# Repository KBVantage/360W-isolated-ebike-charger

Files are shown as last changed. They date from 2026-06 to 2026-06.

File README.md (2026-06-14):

# 360W E-Bike Charger

A high-efficiency isolated AC-DC charger designed for a 24V 100Ah LiFePO4 battery pack used in e-bike applications.  
The charger accepts universal single-phase AC input from 110–230 Vrms, performs EMC filtering and rectification, converts the power through an LLC resonant stage, and regulates battery charging using CC/CV control coordinated with the BMS.



The design achieves up to 24V at 15A peak output current with approximately 94% efficiency at the operating point.  
The control and monitoring architecture uses an STM32L0 microcontroller, while Python scripts were used to support test automation and measurement analysis.  
Design capture was done in Altium Designer, circuit verification was supported with LTspice, and firmware development used STM IDE.

---

## Overview

This project documents the complete development flow of a 360W isolated e-bike charger, from initial specification through schematic design, simulation, PCB layout, validation, and thermal testing.  
The architecture was chosen to deliver efficient battery charging for a 24V LiFePO4 pack while maintaining isolation, safety, EMC performance, and reliable current regulation.  
The battery charging profile follows the CCCV method through communication with the BMS, allowing the charger to gradually increase current and then transition into constant-voltage regulation when the battery approaches its target voltage.

---

## Design Flow

This repository is organized to reflect the engineering process used to develop the charger:

1. Define specifications and operating targets.
2. Build the system block diagram.
3. Select and size power-stage components.
4. Simulate critical circuits in LTspice.
5. Capture the schematic and PCB in Altium Designer.
6. Develop embedded control and measurement firmware in STM32 IDE.
7. Assemble the PCB and generate manufacturing files.
8. Validate the prototype with bench testing and thermal measurements.
9. Analyze measured data with Python automation.

This structure is intended to show not only the final design, but also the reasoning behind each stage of the implementation.

---

## Specifications

### Input
- 110–230 Vrms, single-phase AC input.
- EMC filter at the input stage.
- Common-mode filtering for conducted noise reduction.
- 10A fuse protection.
- Bulk capacitance after rectification.
- Bridge diode rectifier.

### Power conversion
- LLC resonant converter for isolated power transfer.
- High-voltage primary MOSFETs rated 650V, TO-247 super-junction devices.
- Transformer optimized for the required power and isolation.
- Synchronous rectification on the secondary side with SR controller.
- 60V LFPAK56 MOSFETs on the secondary rectifier.

### Output and battery interface
- 24V LiFePO4 battery pack, 100Ah.
- BMS communication for CCCV charging control.
- Peak output current: 15A.

### Control and low-voltage power
- STM32L0 microcontroller for system monitoring and charge control.
- 12V, 5V, and 3.3V rails generated from the battery side using buck regulators and LDOs.
- Isolation used where required for safety and signal integrity.

---

## System Architecture

The charger begins with the AC input stage, where EMI and common-mode filtering reduce noise before the line is protected by a fuse and rectified by a bridge diode stage.  
The rectified DC bus is smoothed with bulk capacitance and then processed by the LLC resonant converter, which provides efficient isolated power transfer at 360W.  
The transformer transfers energy across the isolation barrier, and synchronous rectification on the secondary side improves efficiency compared to passive rectification, especially at higher current.

The battery-side control system communicates with the BMS to coordinate CCCV charging.  
Current and voltage are measured at multiple stages of the power path so the charger can regulate the output safely and transition smoothly through the charging phases.  
Low-voltage housekeeping supplies are derived from the battery side using buck converters and LDOs to power the MCU and auxiliary circuitry.

---

## Component Selection

### Input stage
The fuse was selected to protect the charger against abnormal current conditions and fault scenarios.  
The EMC filter and common-mode choke were chosen to reduce conducted emissions and improve input-side noise suppression.  
Bulk capacitance was sized to support the rectified bus ripple and maintain stable energy storage after the bridge rectifier.

### Primary power stage
The primary switches are 650V TO-247 super-junction MOSFETs selected for voltage margin, thermal robustness, and availability during early hardware bring-up.  
This stage is planned for a later GaN update to further reduce switching losses and improve power density.  
The LLC topology was selected because it offers soft-switching behavior and high efficiency at medium power levels.

### Secondary power stage
The synchronous rectifier uses 60V LFPAK56 MOSFETs chosen for low conduction loss and compact package size.  
The SR controller manages timing to reduce diode-like losses on the secondary side and improve thermal performance.  
This is especially useful in a 24V, 15A charger where secondary conduction losses become significant.

### Control and sensing
The STM32L0 was selected for its low-power operation, compact integration, and flexible peripheral set.  
It supports the measurement, sequencing, communication, and supervisory logic needed for a charger platform.  
Its ultra-low-power characteristics also make it suitable for auxiliary management and standby behavior.

---

## Charging Method

The charger supports CCCV charging by communicating with the BMS (19 V to 29.2 V according to the battery charging profile).  
During constant-current operation, the output current is regulated to charge the battery quickly and safely.  
As the battery voltage rises, the charger transitions into constant-voltage mode, gradually reducing current while maintaining the target voltage until the battery is nearly full.

This approach is well-suited to LiFePO4 chemistry because the battery benefits from controlled charging and stable voltage limits.  
Measurement of current and voltage at different stages allows the charger to track charging progress and maintain the desired charge profile.  
The result is a controlled and efficient charging process with reduced stress on the battery pack.

---

## Repository Contents

This repository includes the following design artifacts:

- Block diagram.
- Schematic files.
- PCB layout files.
- 3D STEP files.
- BOM.
- Manufacturing outputs.
- Simulation files.
- Measurement results.
- Thermal images.
- Waveform captures.

These files provide a full record of the design process from concept to validation.

---

## Schematic and Simulation

This section can explain how the simulated waveforms were used to verify resonant tank behavior, switching timing, output ripple, and rectifier performance before hardware fabrication.



Input - CM filter - bridge rectifier - boost PFC Schematic


LLC converter - SR rectifier Schematic


Relay control to connect the battery to the charging schematic.


```md

```

---

## PCB Layout

The PCB layout maintains 3 mm clearance between neutral and live conductors on the primary side, and 6 mm clearance between primary and secondary domains to support the required isolation barrier and reduce risk of electrical breakdown.
The PCB layout was developed with a strong focus on power integrity, EMI control, and safety isolation. High-frequency switching loops were kept as compact as possible, while sensitive measurement, control, and communication traces were routed away from noisy power nodes. The primary and secondary sections were physically separated to support the isolation barrier, with creepage and clearance considered throughout the board layout and transformer interface. Thermal performance was addressed by spreading losses across the board, using copper for heat dissipation, and positioning major power devices to simplify cooling and reduce local hot spots




```md

```

---

## 3D and Mechanical Design



```md

```

---

## Thermal Results
Thermal measurements were taken to identify hotspots across the primary switches, transformer, synchronous rectifier, and auxiliary power components during load testing. The results provide direct feedback on loss distribution and help verify that the layout and cooling strategy are suitable for continuous operation, while also pointing to opportunities for optimization in the next hardware revision.
Vout 24V Iout 5A, 25C ambient



```md

```

---

## Prototype



```md

```

Current and voltage were measured at multiple stages of the converter, including the AC input, rectified DC bus, primary switching stage, secondary output, and battery connection point. This allowed the design to be verified stage by stage, from input power quality and bus stability to transformer transfer behavior, rectifier performance, output regulation, and battery charging response.

During constant-current charging, the charger maintains a near-constant output current while the battery voltage rises gradually. As the battery approaches its target voltage, the system transitions into constant-voltage mode, where the voltage is held steady and the current naturally tapers down until the battery is nearly full.

---

## Test Automation

Python was used to automate test capture, organize measurement data, and assist with result analysis.  
This helped reduce manual effort during iterative validation and made it easier to compare test runs across multiple operating points.  
The combination of Python and bench instrumentation improved repeatability and allowed faster debugging during bring-up.

Example test activities:
- Capture voltage and current waveforms.
- Log thermal data.
- Compare simulated and measured results.
- Generate plots for design review.

---

## Future Improvements

Planned enhancements for the next revision include:

- Replacing primary MOSFETs with GaN devices.
- Further optimizing efficiency at light load.
- Improving thermal spreading and airflow paths.
- Expanding BMS communication features.
- Refining EMI performance and layout optimization.
- Adding more diagnostic and telemetry functions in firmware.

---

## Software Tools

The following tools were used in the design process:

- Altium Designer for schematic and PCB design.
- LTspice for circuit simulation.
- STM IDE for embedded firmware development.
- Python for test automation and data analysis.

---

## Summary

This 360W e-bike charger project demonstrates a full hardware development flow from specification to validated prototype.  
It combines high-efficiency isolated power conversion, battery-aware CCCV control, embedded supervision, and structured validation.  
The repository is organized to show both the final implementation and the engineering reasoning behind each design stage.

---

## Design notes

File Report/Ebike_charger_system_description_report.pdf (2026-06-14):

# Design of a 360W isolated ebike charger (AC to DC charger)

### Kaone Bogopa, Applications Engineer - Vantage Power

### March 12, 2024

### Abstract

This report presents the complete design and validation of a high-efficiency isolated AC–DC battery charger for 24 V, 100 Ah LiFePO4 battery packs in e-bike and electric mobility applications. The charger accepts universal single-phase AC input from 110–230 Vrms, incorporates EMI filtering and full-bridge rectification, and converts power through a half-bridge LLC resonant stage optimized for soft-switching operation and minimal switching losses. The system delivers a regulated 24 V output at 15 A nominal current, achieving 94Charging is controlled via a constant-current/constant-voltage (CC/CV) algorithm coordinated with the battery management system (BMS) to ensure safe, precise, and optimized charging of LiFePO4 cells. Digital control, real-time monitoring, and fault protection are implemented using an STM32L0 microcontroller, enabling flexible control-loop tuning and advanced protection features. Hardware design, including schematic capture and PCB layout, was developed in Altium Designer, with circuit validation supported by LTspice simulations. Python-based automation tools were used for test execution, data acquisition, and measurement analysis, ensuring repeatable validation and production readiness. The report details measurement techniques, implementation scenarios, and system-level integration for a fully functional, production-ready charger.
This design demonstrates a scalable, high-efficiency charging solution for modern electric mobility systems, combining robust power electronics, intelligent digital control, and manufacturable implementation.

## Contents

### 1 Introduction

This report documents the complete development methodology of a 360 W isolated AC–DC battery charger for 24 V LiFePO4 battery packs in e-bike and light electric mobility applications. The design process encompasses initial specification, system architecture selection, schematic capture, circuit simulation, PCB layout, experimental validation, and thermal performance characterization.

The power conversion architecture employs a half-bridge LLC resonant topology with galvanic isolation, selected for its high efficiency, soft-switching operation (zero-voltage switching for primary MOSFETs and zero-current switching for secondary rectifiers), and excellent electromagnetic compatibility (EMC) performance. The converter accepts universal single-phase input from 110–230 Vrms, input EMI filtering and rectification, and delivers a regulated 20 - 29 V output at 15 A nominal load current with 94% efficiency at the nominal operating voltage.

Battery charging follows a constant-current/constant-voltage (CC/CV) profile, coordinated with the battery management system (BMS) via communication interface. The charger operates in constant-current mode during the bulk charging phase, gradually increasing cell voltage, then transitions to constant-voltage regulation as the battery approaches its target voltage (typically 28.8 V for a 24 V LiFePO4 pack). This charging strategy ensures optimal charging, and prevents overcharging or thermal runaway conditions.

Digital control, real-time monitoring, and fault protection are implemented using an STM32L0 microcontroller, enabling adaptive control-loop tuning, comprehensive protection features (over-voltage, over-current, over-temperature, short-circuit), and flexible system integration. The hardware design was developed in Altium Designer, with circuit-level validation performed using LTspice simulations, and test automation supported by Python-based data acquisition and analysis tools.

This work presents a scalable charging solution that combines high-efficiency power electronics, intelligent digital control, and robust system-level integration.

### 2 Design Flow

This report presented the complete engineering development methodology for the 360 W isolated AC–DC e-bike charger, structured to reflect industry-standard power electronics design practices. The workflow demonstrated a systematic approach from initial specification through final validation, showcasing both technical rigor and production readiness.

- Specification Definition: Defined electrical specifications, operating conditions, and performance targets including input voltage range (110–230 Vrms), output power (360 W), efficiency target (≥ 94%), and safety/regulatory requirements.
- System Architecture: Developed the system block diagram selecting LLC resonant topology with galvanic isolation, CC/CV control strategy, and BMS communication interface.
- Power-Stage Component Selection: Calculated and selected critical power components including MOS-FETs, resonant inductor (Lr), resonant capacitor (Cr), transformer (turns ratio, core selection), output rectifiers, and passive filtering components based on datasheet specifications and application notes.
- Circuit Simulation: Performed circuit-level validation using LTspice for transient analysis, soft-switching verification (ZVS/ZCS), efficiency estimation, and stability assessment of the control loop.
- Schematic and PCB Design: Captured the schematic and executed PCB layout in Altium Designer, incorporating proper impedance control, thermal management, EMC considerations, and high-voltage isolation creepage/clearance requirements.
- Embedded Firmware Development: Implemented digital control loops, BMS communication protocol, real-time monitoring, and fault protection algorithms using STM32L0 microcontroller in STM32 IDE (C/C++).
- PCB Assembly and Manufacturing: Generated manufacturing files (Gerber, BOM, pick-and-place), assembled the PCB, and prepared for prototype validation.
- Prototype Validation: Conducted comprehensive bench testing including input/output characteriza-

360 W isolated e-bike charger
This document belongs to Vantage Power

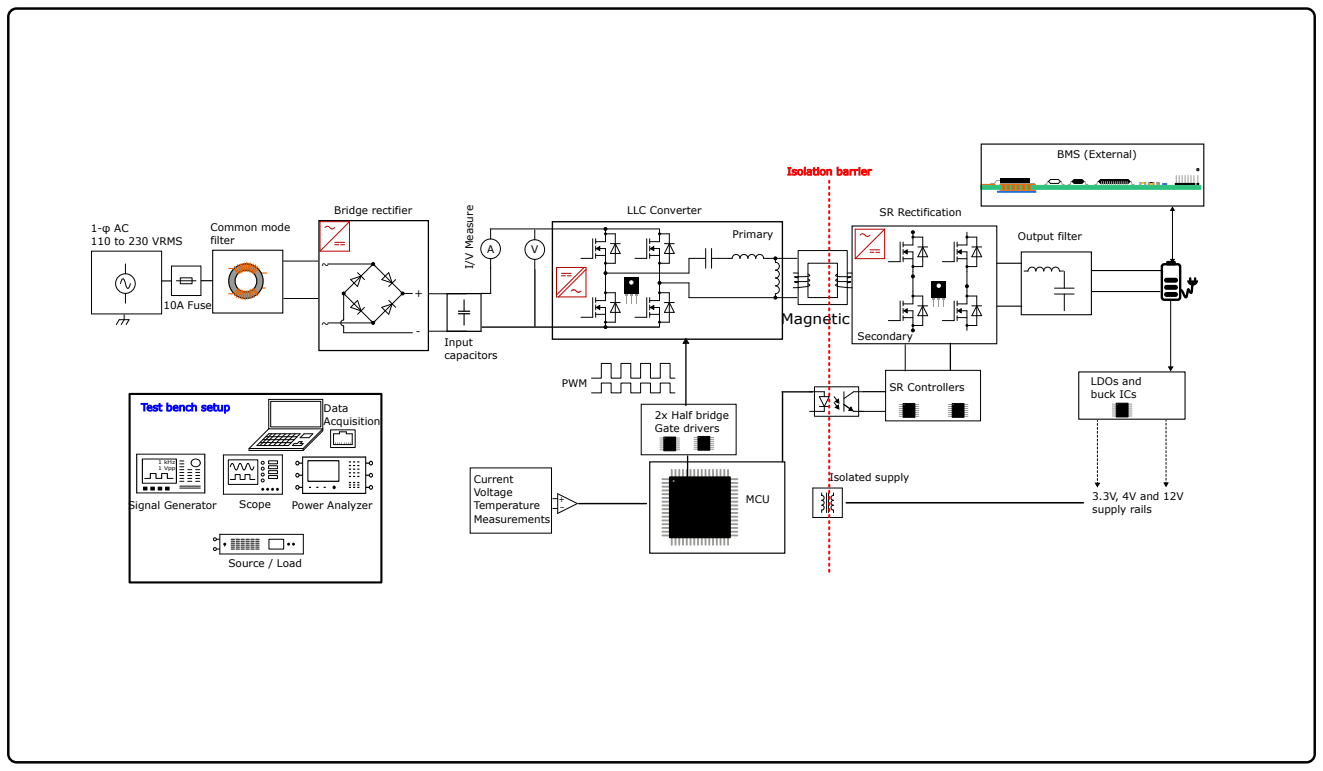
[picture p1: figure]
LLC Converter; Primary; Bridge rectifier; Input capacitors; PWM; Current Voltage Temperature Measurements; Common mode filter; 1-φ AC 110 to 230 VRMS; 10A Fuse; 1 kHz 1 Vpp; Signal Generator; Scope; Source / Load; Power Analyzer; Magnetic; I/V Measure; SR Rectification; SR Controllers; Isolated supply; Secondary; LDOs and buck ICs; Output filter; 2x Half bridge Gate drivers; BMS (External); 3.3V, 4V and 12V supply rails; MCU; Test bench setup; Data; Acquisition; Isolation barrier

Figure 1: E-bike charger block diagram that was adopted

tion, efficiency measurement, load/transient response, EMC pre-compliance, and thermal performance characterization using calibrated instrumentation.

This structured approach demonstrated not only the final design outcome but also the engineering rationale, design trade-offs, and validation methodology behind each implementation stage—reflecting professional engineering practice suitable for production deployment.

### 3 Specifications

The following specifications were provided by the client for the 360 W isolated AC–DC e-bike charger. These define the electrical, safety, and performance requirements for the system.

### 3.0.1 Input Requirements

- Input voltage: 110–230 Vrms single-phase AC, universal input range.
- EMI/EMC filtering: Input-stage EMC filter compliant with IEC 61000-4-6 for conducted emissions reduction.
- Common-mode filtering: Common-mode choke for noise attenuation and conducted interference suppression.
- Protection: Input fuse protection for over-current and short-circuit safeguarding.
- Rectification: Full-bridge diode rectifier for AC-to-DC conversion.
- Bulk capacitance: High-voltage bulk capacitor following rectification for DC bus stabilization.
- Power Factor Correction: Boost-type PFC stage to achieve power factor ≥ 0.9 and reduce input current harmonics.

### 3.0.2 Power Conversion Architecture

- Topology: Half-bridge LLC resonant converter for isolated power transfer with soft-switching operation (ZVS/ZCS).
- Primary MOSFETs: 650 V super-junction MOSFETs in TO-247 package for high-voltage primary switching, optimized for low RDS(on) and fast switching characteristics.
- Transformer: High-frequency isolated transformer optimized for 360 W power transfer, galvanic isolation ≥ 4 kV, and minimal leakage inductance.
- Secondary rectification: Synchronous rectification (SR) using SR controller for improved efficiency and reduced conduction losses.
- Secondary MOSFETs: 60 V LFPAK56 MOSFETs on the secondary rectifier stage, selected for low RDS(on) and compact footprint.

### 3.0.3 Output and Battery Interface

- Battery type: 24 V LiFePO4 battery pack, 100 Ah capacity.
- BMS communication: Digital communication interface with battery management system for CCCV (constant-current/constant-voltage) charging control and safety monitoring.
- Output voltage: Regulated 24 V nominal (charging target: 28.8 V for LiFePO4 pack).
- Peak output current: 15 A maximum continuous charging current (360 W nominal power).

### 3.0.4 Control and Low-Voltage Power Supply

- Microcontroller: STM32L0 ARM Cortex-M0+ microcontroller for digital control loop implementation, system monitoring, BMS communication, and fault protection.
- Voltage rails: 12 V, 5 V, and 3.3 V supply rails generated from the battery-side DC bus using buck regulators and LDOs for gate drive, analog sensing, and digital logic.
- Isolation: Galvanic isolation implemented for high-voltage safety, signal integrity, and compliance with IEC 60950-1/IEC 62368-1 safety standards.

### 4 Block Diagram

Figure 1 presents the complete system block diagram of the 360 W isolated AC–DC e-bike charger, illustrating the power flow architecture, control subsystems, and interface connections. The design follows a two-stage power conversion approach: (1) an input stage with EMC filtering, rectification, and active boost PFC, and (2) an isolated LLC resonant converter with synchronous rectification.

This architecture was selected to achieve high efficiency, galvanic isolation, and excellent EMC performance while meeting IEC 61000-3-2 harmonic current limits.

### 4.0.1 Input Stage: EMC Filtering and Rectification

The input stage begins with an EMI/EMC filter incorporating a common-mode choke to attenuate conducted noise and reduce radiated emissions. This filter serves three critical functions: (1) minimizing radiated and conducted noise on the AC input, (2) reducing the effects of voltage transients from the input source, and (3) protecting the input conductors if a supply failure occurs. The common-mode filter specifically targets conducted noise by presenting high impedance to common-mode currents while allowing differential-mode AC power to pass with minimal attenuation.

Following the EMC filter, a full-bridge diode rectifier converts the AC input to pulsating DC. The bridge rectifier is required for AC–DC power supplies and enables universal input operation (110–230 Vrms). A bulk capacitance following rectification stabilizes the DC bus and filters high-frequency ripple. An inrush current limiter is placed in series with the input to limit the surge current during initial capacitor charging, which can otherwise be 100×greaterthanthenormaloperatingcurrent.

### 4.0.2 Active Power Factor Correction (Boost PFC)

Figure 2: Boost converter topology for the PFC
The boost-type PFC stage is implemented as an active power factor correction circuit to achieve power factor greater than 0.9 and reduce input current harmonics per IEC 61000-3-2. Active PFC brings the power supply’s power factor close to 1.0 by shaping the input current waveform to follow the input voltage waveform, thereby minimizing reactive power and harmonic distortion. This stage is critical for meeting regulatory requirements and reducing stress on the AC mains infrastructure.

Why boost PFC over passive PFC?

Passive PFC using inductors can achieve power factor approximately 0.7–0.8 but requires large, heavy magnetic components and provides limited harmonic attenuation. Active boost PFC achieves power factor greater than 0.95 at compact size and provides a regulated high-voltage DC bus (typically 380–400 V) for the subsequent LLC stage. The regulated DC bus also enables the LLC converter to operate with consistent gain characteristics across the universal input range, which is essential for maintaining ZVS conditions. For e-bike chargers requiring compact size and regulatory compliance, active PFC is the industry-standard choice.

### 4.0.3 Isolated Power Conversion: LLC Resonant

Converter

Figure 3: LLC converter topology The half-bridge LLC resonant converter forms the core power conversion stage, providing isolated power transfer with soft-switching characteristics. The LLC topology was selected over alternative isolated topologies for specific technical reasons.

LLC vs. Hard-Switched Flyback: Flyback converters

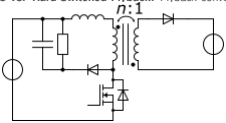
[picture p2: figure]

Figure 4: flyback topology

are simple and cost-effective for low-power applications (less than 100 W) but suffer from high switching losses, poor efficiency.

LLC vs. Phase-Shifted Full-Bridge:

Phase-shifted full-bridge converters offer high efficiency

Figure 5: PFSB topology
and power handling but require complex control (four MOSFETs with precise phase timing) and have higher component count. LLC uses only two primary MOSFETs with simpler frequency-control implementation while achieving comparable efficiency (≥ 94%). For 360 W e-bike charger applications, LLC provides the optimal balance of efficiency, complexity, and cost.

The primary MOSFETs (650 V super-junction devices in TO-247 package) are optimized for low RDS(on) and fast switching characteristics, enabling efficient high-frequency operation (50–200 kHz). Super-junction MOSFETs provide lower RDS(on)

. A product compared to conventional MOSFETs, reducing conduction losses.

The high-frequency isolated transformer is optimized for 360 W power transfer with galvanic isolation ≥ 4 kV and minimal leakage inductance. The transformer serves as the isolation barrier and provides voltage transformation from the high-voltage DC bus to the 24 V output. Parasitic capacitance between primary and secondary windings is a potential EMI source that must be addressed through proper winding layout and shielding.

### 4.0.4 Secondary Rectification: Synchronous Rectifi-

cation (SR)

The synchronous rectification (SR) stage uses actively controlled MOSFETs instead of diodes for output rectification, providing:

- Reduced conduction losses: MOSFET RDS(on) is
significantly lower than diode forward voltage drop Vf
- Higher efficiency: SR can achieve 1–2% efficiency improvement over diode rectification at 15 A output
- Lower thermal stress: Reduced power dissipation decreases heat generation on the secondary side

Why SR over diode rectification? At 15 A output current, a typical Schottky diode with Vf ≈ 0.5 V dissipates

P = Vf × I = 0.5 × 15 = 7.5 W.

Using two diodes in full-wave configuration doubles this to 15 W. In contrast, a 60 V LFPAK56 MOSFET with RDS(on) = 10 mΩ dissipates

P = I

2 × RDS(on) = 15² × 0.01 = 2.25 W.

This represents an 85% reduction in rectification losses, directly contributing to the 94% system efficiency target. SR is essential for high-current, high-efficiency applications.
The 60 V LFPAK56 MOSFETs on the secondary rectifier are selected for low RDS(on) and compact footprint. The LFPAK56 package provides excellent thermal performance with low junction-to-case resistance, enabling efficient heat dissipation.
The SR controller monitors the transformer secondary voltage and drives the MOSFETs with precise timing to achieve ZCS, minimizing reverse-recovery losses.

### 4.0.5 Output Filter and Battery Interface

The output filter consists of capacitors (and optionally a series inductor for L-filter or Pi-filter configuration) to suppress AC ripple superimposed on the DC output. Without output filtering, the peak-to-peak ripple magnitude would equal the DC voltage, which is unacceptable for battery charging. The filter components are placed close to the battery connection to minimize voltage drop caused by load current variations.

The battery interface includes relays for safe connection/disconnection of the battery pack. The relays enable fault isolation (over-current, over-voltage, short-circuit) and support the CCCV charging algorithm by controlling current flow during the charging phases. Connection to the

### 24 V LiFePO4 battery pack (100 Ah) is managed through

the BMS communication interface.

### 4.0.6 Control Subsystem: MCU, Gate Driver, and Sen-

sors

The STM32L0 microcontroller (ARM Cortex-M0+) implements the digital control loop, system monitoring, BMS communication, and fault protection algorithms. The STM32L0 was selected for its:

- Low power consumption (suitable for battery-side control power)
- Adequate PWM resolution and frequency for LLC control (up to 32 MHz clock, 16-bit PWM)
- Built-in ADC channels for current/voltage sensing (12-bit, 2.5 MS/s)
- Communication interfaces (UART/I2C) for BMS interface

Why digital control over analog?
Analog control using PWM controllers (e.g., UC384x family) is simpler but lacks flexibility for adaptive control, complex protection algorithms, and BMS communication. Digital control enables:
(1) adaptive gain tuning for LLC operating across resonant frequency,
(2) comprehensive fault detection with programmable thresholds,
(3) firmware updates for field bug fixes, and
(4) direct BMS communication protocol implementation (e.g., CAN, UART).

For modern e-bike chargers requiring smart features and regulatory compliance, digital control is the preferred approach.
The gate driver circuit provides isolated drive signals to the primary MOSFETs, ensuring proper switching timing and protecting the MCU from high-voltage transients. Gate driver isolation is critical for safety and signal integrity in isolated power converters.

Current and voltage sensors (typically Hall-effect sensors or resistive dividers with isolation) provide feedback for the control loop. The current sensor monitors output charging current for CC mode regulation, while the voltage sensor monitors output voltage for CV mode regulation and BMS communication validation.

### 4.0.7 Low-Voltage Power Supply: Buck Regulators

and LDOs

The low-voltage rails (12 V, 5 V, and 3.3 V) are generated from the battery-side DC bus using buck regulators and

LDOs:

- 12 V rail: Powers gate drivers, SR controllers, and relay coils
- 5 V rail: Supplies analog sensing circuits and peripheral interfaces
- 3.3 V rail: Provides logic power for the STM32L0 MCU

Why buck regulators over linear regulators?
Linear regulators (e.g., 78xx series) dissipate power as heat:

Ploss = (Vin − Vout) × Iout.

For 24 V to 3.3 V conversion at 100 mA, a linear regulator dissipates

P = (24 − 3.3) × 0.1 = 2.07 W,

requiring significant heatsinking. Buck regulators achieve 85–95% efficiency, dissipating only 0.1–0.15 W for the same conversion. For battery-side control power where efficiency and thermal management are critical, buck regulators are essential.
Buck regulators provide efficient DC–DC conversion from the higher battery voltage to required logic levels, while LDOs provide clean, low-noise power for sensitive analog and digital circuits.

### 4.0.8 Thermal and Performance Considerations

The block diagram architecture directly impacts thermal performance and system efficiency:

- Primary side thermal load: LLC resonant operation with ZVS minimizes MOSFET switching losses, reducing primary-side heat generation. The TO-247 package provides adequate thermal dissipation for 650 V, 2–3 A primary current.
- Secondary side thermal load: SR with ZCS minimizes rectifier losses. The LFPAK56 package’s low junction-to-case resistance enables efficient heat transfer to the PCB thermal copper.
- Transformer thermal design: High-frequency operation reduces transformer size but increases core loss. The transformer is optimized for minimal leakage inductance and appropriate core material (ferrite) to balance efficiency and size.
- PFC stage thermal load: The boost PFC dissipates ≈ 2–3 W at 360 W output (assuming 97–98% PFC efficiency), requiring adequate copper area and possibly a small heatsink.

Overall system efficiency of 94% at 15 A output corresponds to ≈ 22 W total power dissipation, which must be managed through PCB thermal copper, component placement, and potentially ventilation or forced air if enclosure thermal resistance is high.

### 4.0.9 Test Instrumentation and Validation Points

The block diagram indicates test instrumentation connection points for prototype validation:

- Input AC voltage and current (for power factor and efficiency measurement)
- DC bus voltage (after PFC)
- LLC switching nodes (for ZVS/ZCS verification)
- Output voltage and current (for CC/CV regulation validation)
- Temperature sensors (MOSFETs, transformer, PFC components)

These instrumentation points support the Python-based test automation described in the Design Flow section, enabling automated data acquisition and post-processing for performance validation.

### 5 Component Selection

This section details the component selection process for the 360 W isolated AC–DC e-bike charger, including mathematical sizing calculations, part requirements, and recommended packages. Components were selected based on datasheet specifications, application notes, and worstcase operating conditions to ensure reliability, efficiency, and regulatory compliance.

### 5.1 Input Stage

The input stage comprises fuse protection, TVS (transient voltage suppression) diode, common-mode (CM) filter, bridge rectifier, boost PFC stage, bulk capacitors, and current/voltage measurement circuits. Each component is sized and selected as follows.

1. Fuse Protection
Function: Over-current and short-circuit protection for the AC input stage.

Selection Criteria:

- Rated current: Ifuse ≥ 1.5 × Iin,max (for inrush current tolerance)
- Voltage rating: Vfuse ≥ 250 Vrms (universal input)
- Time-current characteristic: Fast-blow for rapid fault response

Calculation:
Maximum input current at lowest input voltage (110 Vrms):

Iin,max =

Pout

Vin,min × ηtotal × PF

=

360
110 × 0.94 × 0.95
= 3.68 A

where ηtotal = 94% is total efficiency and PF = 0.95 is power factor.
Fuse rating:

Ifuse = 1.5 × 3.68 = 5.52 A → Select 6 A fuse

Recommended Part: 6 A, 250 Vrms, fast-blow fuse (e.g., Littelfuse 0215006.MXL)
Package: Axial leaded or PCB-mount radial fuse (e.g., 5 × 20 mm)
2. TVS (Transient Voltage Suppression) Diode Function: Protect input stage from voltage transients and surges (e.g., lightning, switching transients).

Selection Criteria:

- Clamping voltage: Vclamp ≥ 1.2 × Vin,max ×

√
2
- Peak pulse power: Ppp ≥ 1000 W (for IEC 61000-4-5 compliance)
- Breakdown voltage: VBR ≈ Vin,max ×

√
2

Calculation: Maximum AC input voltage: Vin,max = 230 Vrms
Vpeak,max = 230√
2 ≈ 325 V

Clamping voltage:

Vclamp = 1.2 × 325 ≈ 390 V

Recommended Part: 390 V clamping TVS diode (e.g., Littelfuse SA390CA, Bourns CDSF390CA)
Package: SMA (DO-214AC) or SMC (DO-214AA) for high power dissipation.
3. Common-Mode (CM) Filter

Function: Attenuate conducted EMI noise and reduce common-mode currents per IEC 61000-4-6.
Selection Criteria:
- Inductance: LCM ≥ 10 mH (for 10–30 MHz attenuation)
- Rated current: ICM ≥ Iin,max = 3.68 A
- Differential-mode capacitance: CDM ≤ 4.7 (to limit leakage current)

Calculation:
For 50 dB attenuation at 150 kHz (EMI start frequency):

LCM =

Zsource
2πf × 10

attenuation
20

=

50
2π × 150 × 10³

× 10².5

≈ 10 mH

where Zsource = 50 Ω is the standard EMI test impedance.

Recommended Part: 10 mH, 5 A common-mode choke (e.g., TDK DSZV2521A-100M, Wurth Electronics 74437346010)
Package: PCB-mount axial or radial choke (e.g., 25 × 21 mm).
4. Bridge Rectifier

Function: Convert AC input to pulsating DC for PFC stage.
Selection Criteria:
- Repetitive peak reverse voltage: VRRM ≥ 1.2×Vin,max×
√
2
- Average forward current: IF(ave) ≥ 1.5 × Iin,max
- Forward voltage drop: VF ≤ 1.0 V (for efficiency)
- Reverse recovery time: trr ≤ 300 ns (slow-recovery acceptable for 50/60 Hz)

Calculation:

VRRM = 1.2 × 230 ×

√
| 2 = 390 V → Select 600 V

IF(ave) = 1.5 × 3.68 = 5.52 A → Select 8 A

Power dissipation at 3.68 A:

Pbridge = VF×Iin = 0.9×3.68 = 3.31 W (two diodes in series)

Recommended Part: 600 V, 8 A bridge rectifier (e.g., STMicroelectronics STPSC8H065, Vishay VS-80MW60) Package: TO-247 or KBU (for 8 A, requires heatsink with Rth ≤ 5 K/W).

5. Boost PFC Stage

Function: Active power factor correction to achieve PF ≥ 0.95 and regulated 390 V DC bus.

5.1 PFC MOSFET
Selection Criteria:
- Drain-source voltage: VDS ≥ 1.2 × Vbus = 1.2 × 390 = 468 V → Select 600 V
- Continuous drain current: ID ≥ 1.5 × Iin,max
- On-resistance: | RDS(on) | ≤ | 0.5
Ω(forlowconductionloss)
- Switching frequency: fsw ≥ 50 kHz (CCM operation)

Calculation:
PFC MOSFET RMS current (CCM boost):

ID,RMS ≈ Iin,max ×

s
Vbus − Vin,peak

Vbus

= 3.68 ×

r
390 − 325
390
= 1.52 A

With 1.5×margin : ID = 1.5 × 1.52 = 2.28 A → Select 4 A
Conduction loss:

Pcond = I

2
D,RMS × RDS(on)

= 1.52² × 0.2

= 0.46 W

for RDS(on) = 0.2 Ω

Recommended Part: 600 V, 4 A super-junction MOSFET (e.g., Infineon IPW60R045, Onsemi NTH6L020N65SF) Package: TO-247 or TO-220 (requires heatsink for 0.46 W

+ switching loss).

5.2 Boost Diode
Selection Criteria:
- Reverse voltage: VRRM ≥ Vbus = 390 V → Select 600 V
- Average forward current: IF(ave) ≥ Iout =

Pout
Vbus

=

360
390 =
0.92 A
- Reverse recovery time: trr ≤ 50 ns (ultrafast/SiC for CCM)
- Forward voltage: VF ≤ 1.2 V

Calculation: With 2 × margin: IF(ave) = 2× 0.92 = 1.84A→ Select 3 A Diode power loss:

Pdiode = VF × Iout = 1.0 × 0.92 = 0.92 W (SiC diode)

Recommended Part: 600 V, 3 A SiC Schottky diode (e.g., Onsemi CS3D06060L, Wolfspeed C3D06060K). Package: TO-247 or TO-220 (SiC diodes have low loss, small heatsink sufficient).

5.3 Boost Inductor

Selection Criteria:

- Inductance: Lboost for CCM operation at minimum input voltage
- Current rating: IL,max ≥ Iin,max +

∆IL
2
- Core material: Ferrite (for 50–100 kHz)
- Saturation current: Isat ≥ 1.2× IL,max

Calculation:
For CCM at Vin,min = 110 Vrms, fsw = 65 kHz:

Lboost =

Vin,peak × (Vbus − Vin,peak)

fsw × Pout × ∆IL

=

155 × (390 − 155)
65 × 10³ × 360 × 0.2 × 3.68 = 280 µH

where ∆IL = 0.2× Iin,max is 20% ripple current. Peak inductor current:

IL,max = Iin,max +

∆IL
2

= 3.68 +

0.2 × 3.68
2
= 4.05 A

With 1.2 × saturation margin:

Isat = 1.2 × 4.05 = 4.86 A → Select 5 A

Recommended Part: 280 , 5 A ferrite inductor (e.g., PULSE Electronics PLT2815-280K, TDK DSL2520-281K) Package: Axial or radial shielded inductor (e.g., 28 × 15 mm).

5.4 PFC Output Capacitor

Selection Criteria:

- Voltage rating: VC ≥ 1.2× Vbus = 468 V → Select 500 V
- Capacitance: Cbus for hold-up time and ripple voltage
- RMS current rating: IC,RMS ≥ Iout
- Low ESR: ESR ≤ 0.5 Ω(forlowrippleloss) Calculation:
For 10 ms hold-up time at full load:

Cbus =

2 × Pout × thold
V

2
bus − V

2
min
=

2 × 360 × 0.01
390² − 300²
= 3.3 µF

where Vmin = 300 V is the minimum PFC output for LLC operation.
Ripple voltage (with ESR = 0.3 Ω) :
∆Vripple = Iout × ESR = 0.92 × 0.3 = 0.28 V (negligible)

Recommended Part: 500 V, 3.3 µ F film capacitor (e.g., Vishay 238D335X5500, WIMA WQP335K500) Package: Radial film capacitor (e.g., 20 × 35 mm).

6. Bulk Capacitors (After Bridge Rectifier)

Function: Stabilize DC bus before PFC stage and filter high-frequency ripple.
Selection Criteria:
- Voltage rating: Vrated ≥ 1.2× Vin,max×

√
2 = 390 V →
Select450V.
- Capacitance: Cbulk ≥ 1 µF/Wforripplef iltering.
- RMS current: IC,RMS ≥ Iin,max.

Calculation:

Cbulk = 1 µF/W × 360 W = 360 µF

Select 2 × 220 µF

Recommended Part: 450 V, 220 µ F electrolytic capacitor (e.g., Nichicon UXW450221, Panasonic EEU-FC450221).
Package: Radial electrolytic (e.g., 25 × 40 mm), use 2 in parallel for current sharing.
7. Current and Voltage Measurement Circuits

7.1 Input Voltage Sensing
Function: Provide scaled AC input voltage feedback to the MCU for PFC control and RMS calculation.

Selection Criteria:

- Voltage divider ratio: VADC =

Vin,peak
N

≤ 3.3 V (MCU
ADC range).
- Impedance: Rtotal ≥ 100 kΩ (for low power loss).
- Precision: ≤ 1% tolerance resistors.

Calculation:

N =

Vin,peak,max

VADC,max

=

325
3.3

= 98.5 → Select N = 100

R1 = 99 kΩ, R2 = 1 kΩ (voltage divider)

Power loss:

Pdivider =

V

2
in,rms
R1 + R2

=

230²
100 × 10³

= 0.53 W

This is acceptable for a 0.5 W to 0.6 W high-voltage resistor string with adequate spacing and thermal margin.

Recommended Part: 99 kΩ, 1 kΩ, 1% tolerance resistors (e.g., Vishay MRS25000, Yageo MFR-25). Package: SMD 2512 for 0.5 W power rating or axial leaded 0.6 W.

7.2 Input Current Sensing

Function: Measure AC input current for PFC control loop and power calculation.

Selection Criteria:

- Sensing method: Hall-effect sensor for AC, noninvasive, or precision shunt resistor.
- Range: Isense ≥ Iin,max = 3.68 A.
- Output: Scaled to 0–3.3 V for MCU ADC.

Calculation:
Using a Hall-effect sensor, for example a 5 A range with 250 mV/A output:

VADC = 3.68 A × 250 mV/A = 0.92 V

This is within the ADC input range.

Recommended Part: 5 A Hall-effect current sensor (e.g., Littelfuse LA55-P, Honeywell CSLA2CD).
Package: PCB-mount through-hole sensor, approximately 20 × 15 × 10 mm.

7.3 PFC Output Voltage Sensing

Function: Monitor the 390 V DC bus for PFC regulation and LLC input validation.

Selection Criteria:

- Voltage divider: N =

390
3.3

= 118 → Select N = 120.
- High-voltage resistors: VR ≥ 200 V per resistor, using series resistors.

Calculation:

R1 = 119 kΩ (use 3 × 40 kΩ in series), R2 = 1 kΩ

Recommended Part: 40 kΩ, 200 V, 1% resistors (e.g., Vishay VSR series) + 1 kΩ, 0.25 W.
Package: SMD 2512 or axial leaded 0.6 W.

7.4 Output Current Sensing

Function: Measure 15 A battery charging current for CC mode regulation.

Selection Criteria:

- Sensing method: Low-RDS(on) MOSFET with current-sense pin or precision resistor.
- Range: Isense ≥ 15 A.
- Power loss: Psense ≤ 0.5 W for efficiency.

Calculation:
Using a precision resistor with Rsense = 5 mΩ:

Psense = I

2

out × Rsense = 15² × 0.005 = 1.125 W

This is too high.
Using Rsense = 2 mΩ:

Psense = 15² × 0.002 = 0.45 W

This is acceptable.
Sense voltage:

Vsense = 15×0.002 = 30 mV → Use an op-amp amplifier with gain 100

Recommended Part: 2 mΩ, 5 W precision current-sense resistor (e.g., Vishay WHPT10, Bourns CRSR-5W). Package: Toggle tab or SMD 2512 for 5 W power rating.

### 5.2 Primary Power Stage

The primary power stage converts the regulated high-voltage DC bus from the boost PFC stage into a high-frequency, approximately sinusoidal waveform suitable for transfer through the LLC resonant tank and isolation transformer. The stage must support soft switching, low circulating energy, low switching loss, and stable operation over the full universal-input range.

Topology Selection

A half-bridge LLC resonant converter is selected for the primary stage because it provides zero-voltage switching (ZVS) for the primary MOSFETs over most of the operating range, which significantly reduces turn-on losses and dv/dt stress. Compared with hard-switched PWM converters, the LLC topology also reduces electromagnetic interference and enables higher switching frequency operation, improving power density. Compared with a phase-shifted full-bridge, it uses fewer primary switches and a simpler control structure, which is appropriate for a 360 W charger.
Selection Criteria:
- DC bus voltage rating: VDS ≥ 1.5 × Vbus to cover nominal bus voltage and switching overshoot.
- Current rating: primary switch current must exceed the resonant tank RMS current with thermal margin.

- Switching performance: low gate charge Qg, low output capacitance Coss, and fast body-diode recovery to support ZVS and low loss.
- Package: thermally robust package with adequate creepage/clearance, preferably TO-247 for prototype and production margin.
- Control compatibility: device must be suitable for high-frequency operation in the 50–200 kHz range, depending on the final resonant design.

Calculations:
For a 360 W output power and assumed full-load efficiency of 94%:

Pin =

Pout
η

=

360
0.94

= 383 W

At a nominal PFC bus voltage of 390 V:

Ibus,avg =

Pin

Vbus

=

383
390

= 0.98 A

The average bus current is not sufficient for switch sizing because the half-bridge primary devices conduct resonant current, not just average DC bus current. A more relevant design quantity is the resonant tank current, which is typically several times the average bus current depending on tank gain, load, and operating frequency. For conservative sizing, the primary MOSFET RMS current should be chosen with at least a 2× margin over the expected resonant RMS current [ref: LLC design guideline].
A practical voltage margin for the MOSFET is:

VDS,rated ≥ 1.5 × 390 = 585 V

so a 650 V device is the minimum reasonable choice.
If the resonant current RMS is estimated at 2.5 A and the MOSFET on-resistance is 0.25 Ω:

Pcond = I

2
rmsRDS(on) = 2.5

2 × 0.25 = 1.56 W

A first-order switching-loss estimate is:

Psw ≈

1
2

VDSIsw(tr + tf)fs

where VDS is the drain-source voltage, Isw is the switching current, tr and tf are effective rise/fall times, and fs is the switching frequency. In LLC operation, this loss is reduced substantially because the MOSFETs are intended to switch near zero voltage [ref: ZVS LLC application note].

The resonant frequency is:

fr =

1
2π

√
LrCr

and the magnetizing-to-resonant inductance ratio is typically selected in the range:

Lm
Lr

≈ 3 to 8

to balance gain range, circulating current, and soft-switching margin [ref: LLC design reference].

Recommended Part: 650 V super-junction MOSFETs with low RDS(on), low Qg, and low Coss,for example devices in the Infineon, onsemi, ST, or Toshiba 650 V family. For the gate driver, use a half-bridge driver with sufficient high-side bootstrap capability or isolated gate drive, depending on the final control architecture.
Package: TO-247 is recommended for the primary MOS-FETs because it offers low thermal resistance, mechanical robustness, and suitable creepage/clearance for a high-voltage prototype. If the design is later optimized for higher power density, a D2PAK or TO-220 variant can be considered, but TO-247 is the safer choice during bring-up and thermal validation.

### 5.3 Transformer and Resonant Tank

Function: The high-frequency transformer provides galvanic isolation, voltage scaling, and power transfer between the primary LLC stage and the secondary rectification stage. The resonant tank components Lr and Cr set the operating frequency of the converter, shape the gain characteristic, and enable soft-switching operation over the intended load range.
Selection Criteria:
- Isolation rating: transformer primary-to-secondary insulation must satisfy the required safety isolation, typically 4 kV reinforced insulation for prototyping and compliance margin.
- Power rating: core and winding structure must support at least 360 W continuous output without excessive temperature rise.
- Leakage inductance control: transformer leakage inductance should be minimized or intentionally designed as part of the resonant tank, depending on

whether Lr

is implemented externally or embedded in the transformer.
- Magnetizing inductance: Lm should be high enough to limit circulating current, but not so high that ZVS is lost at light load.
- Resonant capacitor voltage and current stress: Cr must be a low-loss film capacitor with sufficient RMS current capability.
- Frequency range: the tank should support operation across the required LLC frequency window, typically above and below resonance for gain control.

Transformer Turns Ratio Calculation:

For an output of 24 V nominal and a regulated DC bus of 390 V, the effective turns ratio is selected so that the converter operates near resonance at nominal input and output conditions. For a half-bridge LLC, the primary sees approximately half the bus voltage:

Vpri,eq ≈

Vbus
2

=

390
2

= 195 V

A first-order turns ratio estimate is:

n =

Np
Ns

≈

Vpri,eq

Vout + Vd

where Vd accounts for rectifier or synchronous rectifier drops. For a 24 V output and low-loss synchronous rectification, the effective secondary voltage is close to the battery voltage, so:

n ≈

195
24

= 8.1

A practical design choice is therefore a turns ratio in the range of 7.5:1 to 8.5:1, depending on the final gain curve and desired operating frequency window.

Resonant Frequency Calculation:

The series resonant frequency of the LLC tank is:

fr =

1
2π

√
LrCr

A suitable design target for this charger is a resonant frequency in the 80 kHz to 150 kHz range, which balances transformer size, switching loss, and EMI performance. For the purpose of component sizing, choose a nominal resonant frequency of:

fr = 100 kHz

Resonant Tank Sizing:

The characteristic impedance of the tank is:

Zr =

r
Lr
Cr

A useful first-order approximation for the required tank impedance can be derived from the reflected load resistance. For full-wave rectification with synchronous rectifiers, the reflected load resistance is:

Rac =

8
π

2

n

2Rload

where:

Rload =

Vout

Iout

=

24
15

= 1.6 Ω

Using n = 8:

Rac ≈

8
π

2

× 8

2 × 1.6 ≈ 83 Ω

A common LLC design approach is to choose the tank characteristic impedance lower than the reflected load resistance so that the converter has adequate gain control range. Selecting:

Zr ≈ 12 Ω to 20 Ω

is a reasonable starting point for a 360 W design. Choosing:

Zr = 15 Ω, fr = 100 kHz

the resonant inductance and capacitance are:

Lr =

Zr
2πfr

=

15
2π × 100 × 10³

= 23.9 µH

Cr =

1
2πfrZr

=

1
2π × 100 × 10³ × 15

= 106 nF

A practical implementation would therefore use:

Lr ≈ 24 µH, Cr ≈ 100 nF with the final values adjusted during simulation and prototype tuning.

Magnetizing Inductance Selection:

The magnetizing inductance is typically chosen as:

Lm
Lr

≈ 4 to 6

For Lr = 24 µH, a suitable magnetizing inductance is:

Lm ≈ 120 µH

This gives:
Lm
Lr

=

120
24

= 5

which is a good compromise between gain range and circulating current.

Core Selection:

The transformer core must support the RMS flux density at the selected frequency without saturating. Ferrite is preferred for operation in the 80 kHz to 150 kHz range due to low core loss. The core cross-sectional area and window area should be chosen to accommodate the primary and secondary copper area needed for the required current density, typically 3 A/mm²

to 6 A/mm² depending

on cooling.

A suitable design should also account for:

- Primary copper loss from RMS current and skin-effect at high frequency.
- Secondary winding loss with synchronous rectification current.
- Interwinding capacitance, which should be minimized to reduce common-mode noise.
- Creepage and clearance between primary and secondary windings.

Recommended Part: Custom-wound ferrite transformer, 360 W class, with approximately 8:1 turns ratio, reinforced insulation, and integrated or external resonant inductance as required by the final design. If leakage inductance is used as part of Lr

| , the transformer should be

intentionally designed to target the required leakage value during winding construction.
Package: Ferrite transformer on an E- or ER-type core with bobbin winding, reinforced insulation tape, and PCBmounted or leaded termination depending on the final mechanical design. The resonant capacitor should be a polypropylene film capacitor with low ESR and high RMS current capability, placed close to the primary MOSFET half-bridge to minimize loop inductance.

Implementation Notes The final values of Lr and Cr should be validated in LTspice and then refined on hardware by measuring resonant frequency, gain curve, and ZVS margin. Small deviations from the calculated values are expected because transformer parasitics, diode capacitance, and PCB stray inductance all influence the effective tank parameters.

### 5.4 Secondary power stage

The synchronous rectifier uses 60V LFPAK56 MOSFETs chosen for low conduction loss and compact package size. The SR controller manages timing to reduce diode-like losses on the secondary side and improve thermal performance. This is especially useful in a 24V, 15A charger where secondary conduction losses become significant.

Function: The secondary rectification stage converts the high-frequency AC waveform from the transformer secondary into regulated DC for battery charging. In this design, synchronous rectification is used instead of diode rectification to reduce conduction loss, improve efficiency, and minimize thermal stress at the 15 A output current.

Topology Selection:
Synchronous rectification is preferred over Schottky diodes because the low output voltage makes diode forward-drop losses significant. At 24 V and 15 A, even a modest diode drop would dissipate several watts per device, which would directly reduce charger efficiency and increase heatsinking requirements. MOSFET-based rectification allows the effective forward drop to be replaced by I
| 2RDS(on), which is

substantially lower at this current level.

Selection Criteria:

- Voltage rating: secondary MOSFET VDS ≥ 2×Vout with margin for ringing and leakage spikes.
- Current rating: each rectifier MOSFET must support the full secondary current pulse with adequate thermal margin.
- Low conduction loss: minimum RDS(on) to reduce I

2R

dissipation.
- Fast body diode and low reverse recovery charge to improve commutation behavior.
- Low gate charge Qg for efficient drive and reduced controller burden.
- Package thermal performance: large exposed pad package preferred to spread heat into the PCB copper.

Calculation:

For a 24 V, 15 A output, the rectifier stage must support approximately:

Pout = 24 × 15 = 360 W

A Schottky diode rectifier with a typical forward voltage of 0.5 V would dissipate approximately:

Pdiode = VFIout = 0.5 × 15 = 7.5 W

per conducting diode, and roughly twice that in a full-wave implementation depending on the current path. This level of loss is undesirable for a compact charger.
Using a synchronous rectifier MOSFET with RDS(on) = 10 mΩ:

PSR = I

2

outRDS(on) = 15² × 0.01 = 2.25 W

This is a major reduction relative to diode rectification and is more consistent with the 94% system efficiency target.

If the current is shared between two SR devices, the effective loss per device can be estimated from the conduction duty cycle. For example, assuming each device conducts for half the period and the RMS current per device is approximately 10.6 A:

Pdevice ≈ 10.6

2 × 0.01 = 1.12 W

per MOSFET, which is manageable with proper PCB copper area.

Voltage Rating Margin:

Although the output voltage is only 24 V nominal, secondary-side MOSFETs must withstand leakage spikes, switching transients, and any resonant overshoot during commutation. A 60 V MOSFET is therefore the standard choice:

VDS,rated ≥ 60 V

This provides ample margin above the battery voltage and secondary-side transient conditions.

Gate Drive Requirements:

The synchronous rectifier must be timed so that the MOSFET channel conducts only when current is flowing in the correct direction. The controller should avoid cross-conduction and reverse current flow during commutation. Important requirements include:

- Accurate timing relative to transformer secondary voltage polarity.
- Dead-time insertion to prevent shoot-through.
- Fast turn-off to avoid reverse conduction.
- Stable operation over light-load and full-load conditions.

Recommended Part:A 60 V low-RDS(on) MOSFET in an LFPAK56 or equivalent compact power package is recommended for the synchronous rectifier. Devices in the 5 mΩ to 15 mΩ class are suitable, depending on thermal constraints and gate-drive capability.

Package:
LFPAK56 is preferred because it provides:
- Very low thermal resistance.
- Excellent current handling for compact layouts.
- Low parasitic inductance.
- Strong compatibility with high-density PCB copper heat spreading.

If the thermal design is less constrained, D2PAK or TO-220 alternatives can also be used, but LFPAK56 is the best fit for a compact, high-efficiency charger.

Implementation Notes:
The secondary rectification loop should be laid out with the shortest possible current path between the transformer secondary, MOSFETs, and output capacitors. This minimizes parasitic inductance and reduces ringing at turn-off. Output capacitors should be placed close to the rectifier to absorb commutation ripple and to reduce voltage droop during switching transitions. A dedicated synchronous rectifier controller is recommended to detect current polarity and optimize timing automatically.

### 5.5 Battery Interface and Relay Control

Function: The battery interface provides a safe, controlled connection between the charger output and the LiFePO4 battery pack. It must support controlled connection and disconnection during normal charging, fault isolation during over-voltage or over-current events, and a predictable precharge sequence to limit inrush current into the output capacitors and battery-side wiring. The relay system also prevents uncontrolled arcing at the connector and allows the charger to enter a defined safe state when the battery is removed or the BMS requests shutdown.

Selection Criteria:

- Contact current rating: relay contacts must support at least the maximum continuous charge current with thermal margin.
- Voltage rating: contacts must withstand the maximum battery-side DC voltage and switching transients.
- Coil voltage: must match the available low-voltage control rail, typically 12 V or 5 V.
- Coil power: should be low enough to avoid unnecessary auxiliary dissipation.
- Contact resistance: low enough to minimize I²R loss

and voltage drop at 15 A.
- Isolation: coil-to-contact isolation must satisfy safety and noise-immunity requirements.
- Switching endurance: adequate mechanical and electrical life for repeated charge cycles.
- Control logic compatibility: relay driver must interface cleanly with MCU GPIO or a dedicated low-side driver stage.

Relay Topology:
A practical battery interface for a 24 V charger is a main output relay in series with the positive battery lead, combined with a precharge path in parallel. The main relay is normally open during startup. The precharge path, consisting of a resistor and a smaller relay or transistorcontrolled switch, charges the output capacitors before the main relay closes. This reduces contact stress and prevents a high inrush pulse into the battery-side filter network.

For safety-critical designs, the output disconnect function may be implemented with two relays in series, one on the positive conductor and one on the return conductor, or with a main contactor plus precharge relay depending on the mechanical layout and fault philosophy. A dual-relay arrangement improves fault isolation because a single welded contact cannot leave the pack permanently connected.

Calculation:
At 15 A charging current, the relay contact dissipation is:

Pcontact = I

2Rcontact

If the relay contact resistance is 50 mΩ, then:

Pcontact = 15² × 0.05 = 11.25 W

This is too high for a compact output relay, so a lowerresistance power relay or contactor with a contact resistance in the low milliohm range is preferred. If the contact resistance is 5 mΩ:

Pcontact = 15² × 0.005 = 1.125 W

which is much more acceptable for continuous operation.

Precharge Resistor Calculation:
To limit the inrush current into the output capacitor bank, a precharge resistor is placed in series before the main relay closes. If the battery-side DC bus is 28.8 V maximum and the desired precharge current is limited to 0.5 A:

Rpre =

V
I

=

28.8
0.5

= 57.6 Ω

A standard value of 56 Ω or 68 Ω is suitable depending on the required precharge speed. The resistor power during

precharge is:

Ppre =

V

2
R

=

28.8

2
56

= 14.8 W

so a resistor with at least 25 W pulse capability is recommended, even though the duty cycle is low.

Control Strategy: The MCU controls the relays using a sequenced state machine. The recommended order is:

- Verify battery presence, pack voltage, and BMS permissive status.
- Energize the precharge path and wait until output capacitor voltage approaches battery voltage.
- Close the main relay once the voltage difference is below the selected threshold.
- Disable the precharge path after the main relay is fully closed.
- Continuously monitor output current, output voltage, relay state, and fault inputs during charging.
- Open the main relay immediately on over-voltage, over-current, over-temperature, communication loss, or BMS fault.

Driver Requirements:
The relay coil should not be driven directly from the MCU pin. A low-side N-channel MOSFET or BJT driver stage is preferred, with a flyback diode across the coil to clamp turn-off transients. If the coil is inductive and the switching frequency is low, the driver dissipation is small, but the flyback network is still mandatory to protect the control electronics. A base or gate resistor should be included to limit inrush into the driver device and improve switching stability.

BMS and Interlock Logic:
The relay control must be tied to the BMS permissive signal and charger fault logic. The relay should remain open unless all of the following are true:
- Battery pack voltage is within the safe charging window.
- BMS indicates that charging is allowed.
- No over-voltage, over-current, or over-temperature fault is active.
- The MCU watchdog and control firmware are running normally.

If any permissive signal is lost, the MCU must open the relay and force the converter into a safe shutdown state.

Recommended Part: A PCB-mount power relay or DC contactor rated for at least 30 A continuous current and 60 V DC contact switching, with low contact resistance and a 5 V or 12 V coil depending on the auxiliary rail. For the precharge element, use a wirewound or metal-oxide resistor with pulse capability appropriate for the calculated energy. If a compact solution is preferred, a sealed automotive-style relay or DC-rated contactor is preferable to a small signal relay because the charger current is far above the safe range of general-purpose PCB relays.

Package: Sealed power relay or DC contactor with screw terminals or high-current PCB pins, mounted with adequate creepage, clearance, and thermal spacing from low-voltage control circuitry. The precharge resistor should be mounted to allow heat dissipation and kept away from temperature-sensitive components.

Implementation Notes:
The relay coil driver should include a dedicated flyback diode, local decoupling, and, if needed, a transistorized enable stage so the MCU can cleanly disable the output in firmware. Relay contact routing should minimize loop area and resistive loss, and the precharge branch should be physically separated from the main current path to simplify fault diagnosis. The charger output should not energize the battery connector until the output capacitors have been precharged and the BMS has authorized charging.

The battery interface should use a main power relay or contactor with a controlled precharge path and MCUdriven coil logic. This arrangement reduces inrush stress, improves connector safety, and provides a deterministic means of disconnecting the battery under fault conditions.

### 5.6 Control Board Component Selection

The control board provides closed-loop regulation, protection logic, measurement acquisition, synchronous rectifier timing, and gate-drive supervision for the charger. It must therefore combine deterministic digital timing, low-noise analog sensing, robust peripheral interfaces, and stable auxiliary power generation. The architecture implemented here uses an STM32L053C8T6 microcontroller as the central control device, Texas Instruments synchronous rectifier controllers, TI buck regulators, and low-noise TI LDOs for the internal rails.

### 5.6.1 Microcontroller Selection

The microcontroller implements the digital control layer for the charger. Its tasks include ADC acquisition of input and output voltage/current feedback, PWM generation for frequency control of the LLC power stage, fault management, communication with the battery-management system, soft-start sequencing, telemetry, and service/debug access.

Selection Criteria:

- Cortex-M0+ core with deterministic interrupt latency for control tasks.
- Multiple ADC channels for simultaneous sensing of input voltage, input current, output voltage, output current, and thermal inputs.
- Timer resources for PWM, frequency modulation, dead-time insertion, and capture/compare timing.
- UART, I²C, and SPI support for debug, BMS commu-

nication, and peripheral expansion.
- Adequate Flash and RAM for closed-loop firmware, calibration tables, protection state machines, and event logging.
- Low-power operating modes to reduce standby consumption.

Selected Part: STM32L053C8T6.

Why this part: The STM32L053C8T6 belongs to the STM32L0 family and provides a low-power Cortex-M0+ core with sufficient timer, ADC, and serial interface resources for a compact power-supply controller. Its 32 MHz operating capability is adequate for control-loop computation, real-time monitoring, and frequency-based LLC control, while its low-power features reduce auxiliary consumption during standby and fault states.

Evaluation Board: NUCLEO-L053R8 is a practical development and firmware-validation board for this family, it was useful for control-loop bring-up, ADC calibration, and peripheral validation before custom PCB deployment.

Sensing and Control Logic:
The MCU receives scaled feedback signals from the input and output sensing circuits. The sensed AC input voltage is rectified or sampled synchronously and converted by the ADC for RMS estimation, mains supervision, and PFC control. Input current feedback is used for average current-mode or peak-current supervision, depending on the final control algorithm. Output voltage feedback is used to regulate the LLC frequency command, while output current feedback enforces constant-current charging during the bulk phase and constant-voltage charging near the end of charge.
The ADC results are processed in firmware using gain and offset calibration coefficients.
The firmware computes the error between the measured quantity and the reference setpoint:

e(t) = xref − xmeas

where xmeas is the sensed voltage, current, or derived RMS quantity. The error is then passed through the corresponding control law, typically PI or gain-scheduled PI for LLC frequency regulation. For the LLC stage, the control output is not duty cycle in the conventional PWM sense, but switching frequency:

fsw = fr + ∆f(e)

where fr

is the resonant frequency and ∆f(e) is the frequency correction generated by the control loop.

PWM and Duty Logic:
For the half-bridge LLC primary stage, the MCU does not vary duty cycle as in a fixed-frequency PWM converter. Instead, it generates complementary gate-drive signals with fixed 50% duty per leg and inserts dead time to prevent shoot-through. Output power is controlled by varying the switching frequency around resonance. When the measured output voltage is below target, the firmware reduces the switching frequency toward resonance or below resonance to increase tank gain. When the output voltage rises above target, the firmware increases switching frequency above resonance to reduce gain and circulating current.

A practical timer configuration is:

- Complementary outputs with programmable dead time for the half-bridge driver.
- Frequency-modulated timer period for LLC control.
- ADC triggering aligned to the PWM cycle for low-noise synchronous sampling.
- Interrupt-based fault shutdown for over-voltage, over-current, over-temperature, and loss-of-feedback events.

For synchronous rectification, the MCU may either supervise a dedicated SR controller or provide enable/disable coordination with the charging state machine. In this design, the SR timing itself is preferably handled by a TI SR controller, while the MCU handles higher-level sequencing and fault responses.

### 5.6.2 Synchronous Rectifier Controller

The synchronous rectifier controller drives the secondary-side MOSFETs to reduce rectification loss and improve efficiency at 15 A output current. It senses the transformer secondary polarity and ensures that the MOSFET channel turns on only when forward current is present.

Selection Criteria:

- Compatible with 24 V output systems and LLC synchronous rectification.
- Drain-source sensing to detect conduction polarity without a separate current transformer.
- High-speed turn-on and turn-off with blanking to suppress false triggering.
- Interlock function to prevent cross-conduction between the two SR MOSFETs.
- Supply and voltage ratings compatible with the secondary-side bias rail.

Calculation:
At 15 A output current, diode rectification is too lossy. Using a representative 0.5 V diode drop:

Pdiode = 0.5 × 15 = 7.5 W

per conducting path. With a 10 mΩ MOSFET:

PSR = 15² × 0.01 = 2.25 W

This makes SR the correct choice for the secondary stage.

Selected Part: Texas Instruments UCC24624.

The UCC24624 is suitable for LLC resonant converter secondary rectification and uses drain-to-source voltage sensing with adaptive proportional gate drive. It includes blanking intervals, interlock logic, and voltage-sensing capability appropriate for low-voltage, high-current outputs such as 24 V battery chargers.
Package: SOIC or small-outline power-control package with short gate and sense routing.

### 5.6.3 Primary Gate Driver

The gate driver drives the half-bridge MOSFETs on the primary side, supplying the peak source and sink current needed for fast transitions at high frequency. It also enforces dead time and protects the power switches from shoot-through.
Selection Criteria:
- Half-bridge support with high-side and low-side drive.
- Strong gate-drive current capability for low total transition loss.
- UVLO to prevent partial enhancement at insufficient supply voltage.
- High dv/dt immunity for operation on a 390 V switching node.
- Compatibility with 10 V to 12 V gate-drive rail.

Calculation:
If one MOSFET has total gate charge Qg = 70 nC, gate voltage VGS = 12 V, and switching frequency fs = 100 kHz, the gate-drive power per device is:

Pgate = QgVGSfs = 70 × 10⁻⁹ × 12 × 100 × 10³ = 0.084 W

This is small individually, but the driver and supply rails must still be sized for transient current and noise immunity.

Recommended Part: A TI half-bridge gate-driver family part suitable for resonant converters and high dv/dt operation.
Package: SOIC-8 or QFN with local bootstrap and decoupling capacitors placed close to the device pins.

### 5.6.4 Low-Voltage Regulators

The auxiliary supply generates the board rails used by the MCU, SR controller, gate driver, and sensing analog front-end. The preferred architecture uses a TI synchronous buck regulator for bulk step-down conversion and a TI LDO for low-noise regulation.
Selection Criteria:
- Buck regulator input range compatible with the available auxiliary supply.
- Output current sufficient for MCU, SR controller, driver bias, and sensor loads.
- High conversion efficiency to minimize heating in the sealed control enclosure.
- LDO output noise low enough for ADC and timingsensitive analog circuitry.
- Good transient response during startup, fault recovery, and state transitions.

Calculation:
If the board requires 12 V at 150 mA from a 24 V input rail:

Pout = 12 × 0.15 = 1.8 W

At 90% efficiency:

Ploss =

1.8
0.9

− 1.8 = 0.2 W

A 12 V to 5 V or 12 V to 3.3 V LDO stage is then used only for the low-current, low-noise rails where linear dissipation is acceptable. For example, 5 V to 3.3 V at 80 mA dissipates:

PLDO = (5 − 3.3) × 0.08 = 0.136 W

Selected Parts:
For the buck stage, a TI synchronous buck regulator such as TPS54202 is a suitable class of device for intermediate rails, while a higher-integration option such as TPSM63603 can be used when a compact power-module implementation is preferred. For the LDO stage, TPS7A44 is attractive because it supports a wide input range and can provide a clean bias rail with low quiescent current.

Package: Use QFN or HTSSOP for the buck regulator and SOT-223, SOT-23, or DFN for the LDO, depending on current and thermal requirements.

### 5.6.5 Interface and Programming

The control board should expose programming and debug interfaces for firmware bring-up, calibration, and fault analysis.
Selection Criteria:
- SWD interface for programming and debugging.
- UART for bootloader or field logging.
- I

2C for sensors and support ICs.

- Test points for all regulated rails and main feedback nodes.

Recommended Part: Standard 0.05-inch or 0.1-inch debug header footprint with labeled pins for SWDIO, SWCLK, NRST, TX, RX, GND, and target voltage. Package: Board-edge header or low-profile debug connector.

### 6 Design creation and Simulation

The LLC converter was first developed and verified in LTspice to validate resonant tank behavior, switching transitions, output ripple, rectifier conduction, and the influence of non-ideal parasitics before hardware implementation. The simulation workflow was used to confirm that the selected resonant parameters, transformer ratio, and semiconductor devices could meet the 360 W output target while preserving zero-voltage switching and acceptable current stress across the intended operating range.

### 6.0.1 Simulation Procedure

The simulation was built in stages rather than as a single full-system model. The first stage modeled only the LLC resonant tank, half-bridge excitation, and transformer equivalent circuit to confirm the approximate resonant frequency, current shape, and gain behavior. In this stage, the resonant inductor Lr

, resonant capacitor Cr

, magnetizing inductance Lm, transformer turns ratio, and bus voltage were defined using the nominal design values derived from the hand calculations.
The second stage added the primary MOSFETs, gate-drive timing, and dead-time interval to check that both switches turned on under near-zero drain-source voltage. This was essential for verifying zero-voltage switching over the expected load window. The switching frequency was

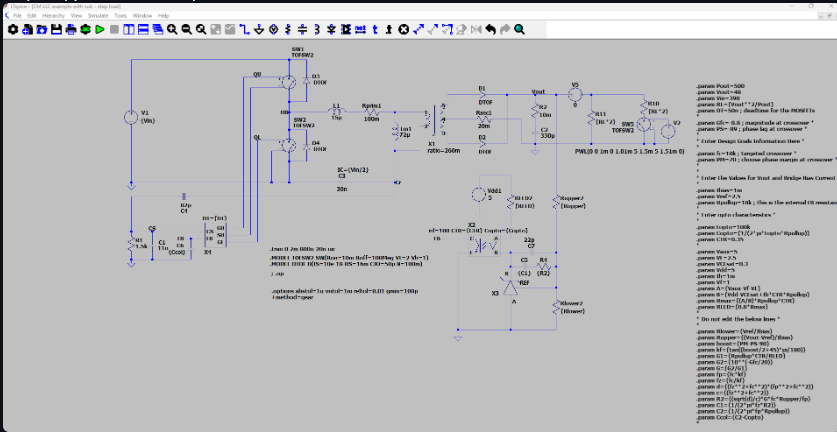
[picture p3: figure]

Figure 6: LTspice simulation model used for LLC converter verification.

then swept around resonance to observe the gain characteristic and determine the operating region required for constant-current and constant-voltage charging.

The third stage added the secondary-side synchronous rectification stage, output capacitor bank, and resistive load. This allowed the output ripple, rectifier current waveform, and secondary conduction timing to be evaluated under light-load, nominal-load, and full-load conditions. Finally, non-ideal elements such as winding resistance, capacitor ESR, MOSFET output capacitance, leakage inductance, and parasitic capacitances were introduced to make the model more representative of the final hardware.

### 6.0.2 Parasitic Modeling

Parasitic components were included because they strongly affect LLC converter performance at high frequency. The transformer winding resistance increases conduction loss and reduces efficiency, while leakage inductance alters the effective resonant tank value and shifts the resonant frequency. The MOSFET output capacitance contributes additional resonant energy that affects turn-on conditions and switching loss. Capacitor ESR and inductor series resistance also modify the Q-factor of the tank and influence output ripple.

The final simulation therefore included the following parasitics:

- Transformer primary and secondary winding resistance.
- Leakage inductance as part of, or in addition to, the resonant inductance.
- MOSFET output capacitance and body-diode behavior.
- Resonant capacitor ESR.
- Output capacitor ESR and equivalent series inductance.
- PCB trace resistance and small loop inductance in the switching paths.

Including these non-idealities allowed the simulated waveforms to better match the expected prototype behavior and reduced the risk of large deviations during hardware bring-up.

### 6.0.3 Key Simulation Checks

The simulation was used to verify several critical design objectives:

- Resonant frequency agreement between the analytical design and the LTspice model.

- Zero-voltage switching on the primary MOSFETs at nominal and near-nominal load.
- Acceptable secondary synchronous rectifier timing and low reverse conduction.
- Output ripple magnitude within the battery-charging requirement.
- Stable gain transition between constant-current and constant-voltage operating regions.
- Reasonable current stress in the primary switches, resonant tank, and secondary rectifiers.

### 6.0.4 Final Design Results

The final LTspice model confirmed that the chosen LLC parameters were appropriate for the 360 W charger. With the selected resonant tank values, the simulated converter operated near resonance at the nominal bus voltage and output load, producing the expected high-frequency waveform at the transformer primary and maintaining soft-switching behavior over the intended operating range.
At nominal operating point, the primary drain-source waveforms showed that the MOSFETs were turned on after the switch-node voltage had fallen close to zero, confirming ZVS. The secondary rectifier currents were also well aligned with the transformer secondary voltage polarity, reducing unnecessary diode conduction and supporting high efficiency. Output ripple remained low enough for battery charging, and the current waveforms remained smooth enough to avoid excessive stress on the transformer and rectifier devices.
The final model also showed that the inclusion of parasitics slightly shifted the resonant frequency downward relative to the ideal analytical value, which is expected in a practical implementation. This shift was compensated by tuning the nominal switching frequency window in firmware and by confirming that the final frequency range still preserved gain control margin. The simulation therefore validated both the selected hardware topology and the control strategy before PCB fabrication.

### 6.0.5 Design Interpretation

The LTspice study confirmed that the converter is best operated with frequency control rather than duty-cycle modulation. The duty ratio of the half-bridge remains approximately fixed, while regulation is achieved by moving the switching frequency relative to resonance. This behavior is consistent with LLC design theory and provides the main mechanism for output regulation, soft switching, and load adaptation.
Overall, the simulation stage demonstrated that the selected resonant tank, transformer ratio, MOSFETs, synchronous rectification strategy, and output filtering network form a technically coherent design. The resulting waveforms and stress levels supported the transition from schematic design to PCB implementation and prototype validation.

### 7 Schematic and PCB Design

The complete electrical implementation of the charger was captured in Altium Designer, beginning with the input front end, followed by the boost PFC stage, the isolated LLC power stage, the synchronous rectifier, the control circuitry, and the auxiliary low-voltage supplies. The schematic was partitioned into functional blocks to improve readability, simplify net management, and allow independent verification of each subsystem before integration. The PCB layout was then implemented as a compact two-layer design with careful attention to creepage, clearance, thermal dissipation, current density, and noise-sensitive routing.

### 7.0.1 Schematic Capture Method

The schematic was developed using a hierarchical structure so that each functional block could be validated independently before system integration. The input protection and EMI network were placed at the front of the design, followed by rectification and PFC conversion, then the LLC resonant power stage, synchronous rectification, control circuitry, sensing circuits, and auxiliary power rails. This approach reduces schematic complexity, improves debug efficiency, and makes it easier to trace power flow and signal flow across the design.
Critical nets such as the AC input, PFC bus, half-bridge switching node, transformer primary, secondary rectified output, and control references were clearly separated and labeled. Net naming was kept consistent with the design calculations so that the schematic, simulation model, and PCB layout could be cross-checked without ambiguity. Power ports and ground references were managed carefully to avoid accidental shorting between the high-voltage primary domain and the isolated secondary/control

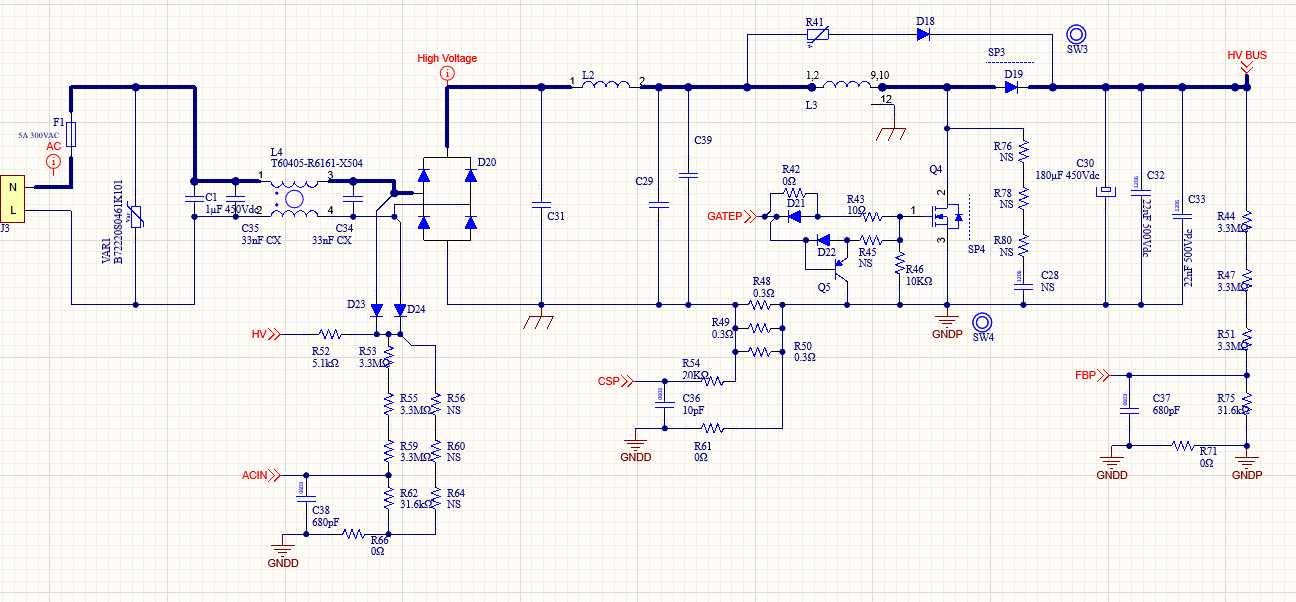
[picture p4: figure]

Figure 7: Altium design of the input front end: connectors, EMI filter, bridge rectifier, and boost PFC.

domain.

### 7.0.2 PCB Design Rules

The PCB was designed as a two-layer board with top-layer component placement optimized for short power loops and bottom-layer copper used as a return path and thermal spreading layer. The main routing rules followed during layout were:

- Maintain sufficient creepage and clearance between the primary side, secondary side, and low-voltage control area.
- Keep high-current paths as short and wide as possible to minimize copper loss and voltage drop.
- Minimize the loop area of switching nodes to reduce radiated and conducted EMI.
- Place decoupling capacitors directly adjacent to the pins of power ICs, gate drivers, and control ICs.
- Separate noisy power ground paths from sensitive analog ground returns and join them at a controlled star point.
- Use thermal vias and large copper pours under devices with significant power dissipation.
- Avoid routing feedback and sensing traces near high dv/dt nodes such as the half-bridge midpoint and transformer primary connections.

The PCB layout was developed with a strong focus on power integrity, EMI control, and safety isolation. The layout maintains 3 mm clearance between neutral and live conductors on the primary side, and 6 mm clearance between the primary and secondary domains to support the required isolation barrier and reduce the risk of electrical breakdown. High-frequency switching loops were kept as compact as possible to minimize parasitic inductance, switching overshoot, and radiated emissions, while sensitive measurement, control, and communication traces were routed away from noisy power nodes.

The primary and secondary sections were physically separated to preserve the isolation barrier, with creepage and clearance considered throughout the board layout and transformer interface. Thermal performance was addressed by spreading losses across the board using copper for heat dissipation, and by positioning major power devices to simplify cooling and reduce local hot spots. This layout approach improves reliability, reduces EMI susceptibility, and supports safe operation under high-voltage conditions.

### 7.0.3 Input Front-End Layout

As shown in Figure 7, the input front end contains the connectors, EMI filter, bridge rectifier, and boost PFC stage.

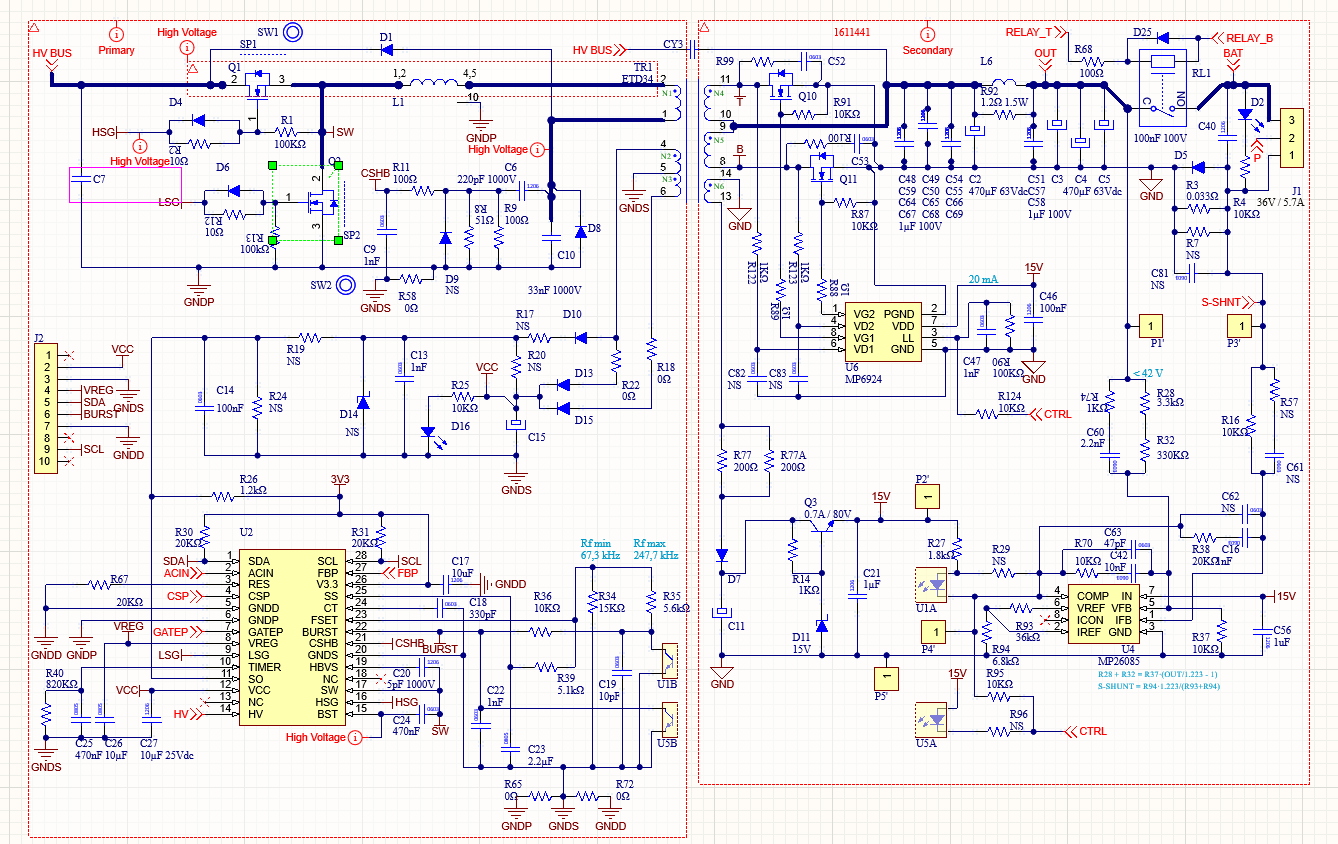
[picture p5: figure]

Figure 8: Altium design of the LLC converter and its magnetics.

These components were placed in the order of power flow to keep the high-current AC and DC paths compact. The EMI filter was positioned immediately after the input connector so that conducted-noise attenuation occurred before the rectifier and PFC stage. The bridge rectifier and boost switch path were then arranged to minimize the current loop formed by the rectifier, boost inductor, switching MOSFET, diode, and bus capacitor.

The boost inductor was placed close to the switching node and bus capacitor to reduce parasitic inductance in the high di/dt path. The PFC current-sense elements were routed with Kelvin-style connections to avoid contamination from power-ground voltage drop. The DC bus capacitors were positioned close to the boost output to limit ripplecurrent loop area and improve transient behavior. Thermal copper was added beneath the bridge rectifier and PFC MOSFETs, with additional vias to transfer heat to the opposite layer.

### 7.0.4 LLC and SR Layout

Figure 8 shows the isolated LLC converter and its magnetics. The LLC resonant tank was placed as close as possible to the primary half-bridge MOSFETs and transformer primary pins in order to minimize loop inductance and improve ZVS performance. The resonant capacitor was placed adjacent to the switching devices, while the resonant inductor and transformer were arranged to reduce current path length and preserve the intended resonant behavior.

The transformer was oriented so that the primary and secondary current paths were well separated on the board, with the secondary rectification devices placed near the transformer secondary pins to minimize the rectifier commutation loop. This is especially important because synchronous rectification depends on low parasitic inductance and accurate switching timing. The SR controller sensing pins were routed away from the switching node and coupled to the transformer secondary with short, low-noise

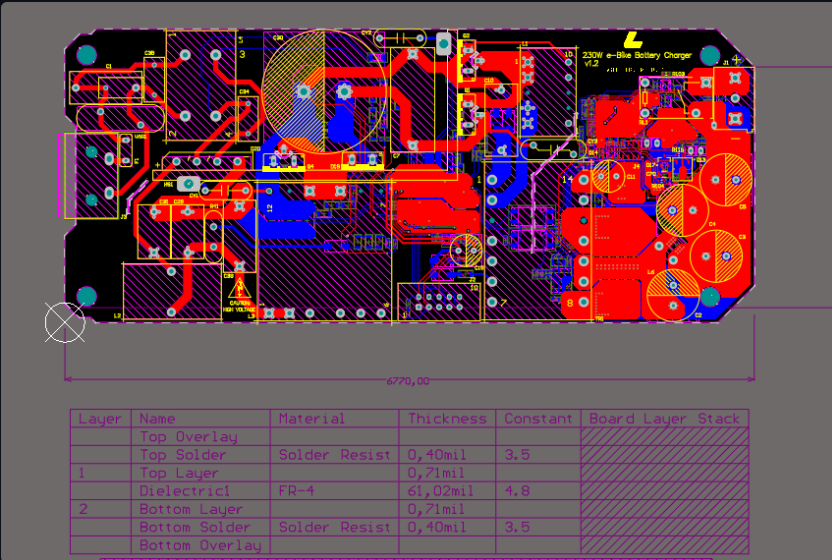
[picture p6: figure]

Figure 9: PCB design in two layers.

traces.

The output capacitors were placed directly after the SR stage to absorb current ripple and stabilize the battery output node. Wide copper pours were used on the secondary high-current path, and multiple vias were placed in parallel where needed to reduce current bottlenecks. The magnetic components were spaced so that airflow and thermal rise would not create hot spots in adjacent control circuitry.

### 7.0.5 Control and Low-Voltage Routing

The control board was isolated from the primary switching region and placed in a quieter area of the PCB. Analog sensing traces from the voltage dividers, current sensors, and temperature sensors were routed away from the half-bridge node and the PFC switching loop. ADC input traces were kept short and were filtered at the source using small RC networks where appropriate. Digital communication lines such as UART, I²C, and SWD were grouped and routed with clear return paths.
The MCU decoupling capacitors were placed immediately next to the power pins, and the crystal or timing source was isolated from high-current traces to avoid jitter and noise injection. The low-voltage rails from the buck and LDO stages were distributed with local bypass capacitors at each IC. To improve robustness, test points were included on the main rails, gate-drive supplies, feedback nodes, and key enable signals.

### 7.0.6 Methods Used in Layout Verification

Several design-verification methods were used before releasing the layout:

- ERC and DRC checks were performed to identify schematic and layout violations.
- Net classes and clearance rules were used to enforce spacing by voltage domain.
- Polygon pour connectivity was verified to ensure low-

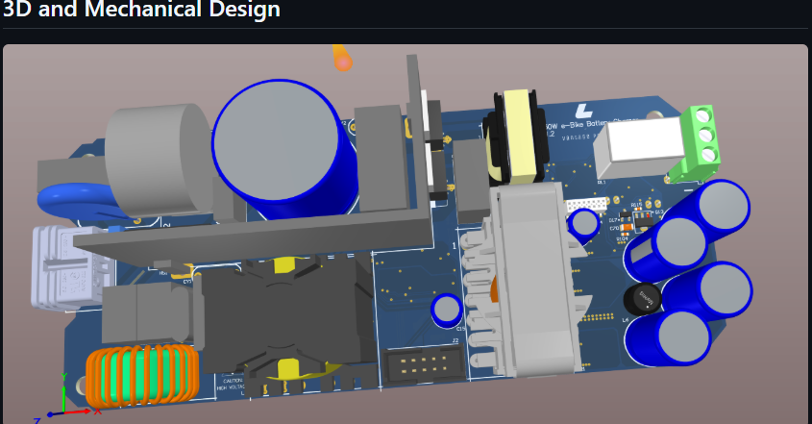
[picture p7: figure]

Figure 10: Three-dimensional view of the completed two-layer PCB layout.

impedance current return paths.
- 3D view inspection was used to confirm component height, spacing, and connector accessibility.
- High-current loop paths were reviewed to reduce EMI and optimize thermal spreading.
- Critical component placement was checked against the thermal model and expected airflow direction.

Figure 9 shows the final two-layer PCB layout, while Figure 10 provides a 3D view of the assembled board. The layout confirms that the power stage, control circuitry, and isolation domains were implemented within a compact footprint while preserving the spacing and routing discipline required for a high-voltage charger.

The schematic and PCB design process in Altium Designer followed a block-based and rule-driven methodology. The layout prioritized high-current loop minimization, thermal management, isolation spacing, and low-noise sensing, while the 3D review and design-rule checks provided an additional layer of verification before fabrication. This implementation strategy produced a manufacturable two-layer board suitable for prototype testing and system validation.

### 8 Embedded Firmware Development

The | embedded | firmware | was | developed | in
STM32CubeIDE for the STM32L0 microcontroller and organized into interrupt-driven control tasks, ADC acquisition routines, communication handlers, fault management, and PWM generation for the power stages. The pin assignment was defined early in the development process to ensure that the ADC channels, timer outputs, serial interfaces, and fault inputs were mapped consistently with the schematic and PCB layout.

### 8.0.1 Microcontroller Pin Assignment

The microcontroller pin map was configured to support analog sensing, frequency control of the LLC stage, synchronous rectifier control, communication interfaces, and protection inputs. Care was taken to keep the most noise-sensitive analog inputs away from switching outputs and to assign timer outputs with the required complementary and dead-time features.

### 8.0.2 Firmware Architecture

The firmware is structured as a real-time state machine with separate modules for startup, precharge, soft-start,

Table 1: STM32 microcontroller pin assignment used in STM32CubeIDE.

Signal | STM32 Pin | Peripheral Function | Description
Input voltage sense | PA0 | ADC IN0 | Scaled AC input voltage feedback
Input current sense | PA1 | ADC IN1 | Input current measurement for PFC control
PFC output voltage sense | PA2 | ADC IN2 | High-voltage DC bus feedback
Output current sense | PA3 | ADC IN3 | Battery charge current feedback
Temperature sense | PA4 | ADC IN4 | NTC or thermal monitoring input
LLC PWM high-side | PA8 | TIM1 CH1 | Complementary half-bridge drive output
LLC PWM low-side | PB13 | TIM1 CH1N | Complementary half-bridge drive output
SR enable / control | PB0 | GPIO Output | Synchronous rectifier control signal
Relay control | PB1 | GPIO Output | Battery relay and precharge control
UART TX | PA9 | USART1 TX | Debug and telemetry output
UART RX | PA10 | USART1 RX | Debug and telemetry input
2C SCL I | PB6 | I2C1 SCL | Sensor or peripheral communication
2C SDA I | PB7 | I2C1 SDA | Sensor or peripheral communication
SWDIO | PA13 | SWDIO | Programming and debugging interface
SWCLK | PA14 | SWCLK | Programming and debugging interface
Fault input | PC13 | GPIO Input | Hardware protection or external fault signal

constant-current charging, constant-voltage charging, fault
handling, and shutdown. ADC sampling is performed either by timer-triggered conversions or periodic interrupts so that voltage and current measurements remain synchronized with the switching and control intervals. The LLC stage is regulated by frequency modulation rather than duty-cycle variation, while complementary PWM outputs are used to drive the primary half-bridge with fixed dead time.

### 8.0.3 Control Loop Operation

The firmware uses the measured input and output signals to compute control errors and update the operating point of the converter. Input voltage and current measurements are used for front-end supervision and PFC-related monitoring, while output voltage and current measurements determine the charging state. The LLC control loop adjusts switching frequency according to the measured error, so the duty cycle on the half-bridge remains fixed while the period is varied to regulate power transfer.
The general control relationship is:

e(t) = xref − xmeas

fsw = fnom + Kpe(t) + Ki

Z
e(t) dt

where fsw is the commanded switching frequency and the PI controller determines the correction required to maintain the desired output voltage or current.

### 8.0.4 Programming and Debugging

The STM32CubeIDE environment was used for pin configuration, peripheral initialization, firmware generation, and debug access. The SWD interface was reserved for flashing and runtime debugging, while UART was used for diagnostics and parameter monitoring during bring-up. This approach simplifies validation of the sensing paths, PWM outputs, relay logic, and protection events before the full charger is energized. The embedded firmware layer provides the digital control infrastructure for the charger, with the STM32 microcontroller acting as the central control device. The pin assignment table defines the interface between the firmware and the hardware, ensuring that sensing, PWM generation, communication, and protection functions are mapped in a way that supports stable and deterministic operation.

### 9 PCB Assembly and Manufacturing

After the schematic capture, firmware bring-up planning, and PCB layout were completed, the final stage was manufacturing and assembly of the printed circuit board. This stage translated the design from CAD into physical hardware while preserving the electrical constraints required for high-voltage power conversion, thermal management, and safe testability. The fabrication workflow was designed with manufacturability, assembly repeatability, and debugging access in mind, using design-for-test (DFT), design-for-manufacturing (DFM), and design-for-assembly (DFA) principles throughout the process.

### 9.0.1 Manufacturing Workflow

The PCB was manufactured through JLCPCB, which provided both board fabrication and component assembly services for the selected design. The manufacturing package was prepared by exporting the final Gerber files, drill files, pick-and-place data, BOM, and assembly drawings from Altium Designer. These files were reviewed before submission to ensure that pad geometry, component orientation, polarity markings, and reference designators were consistent across the schematic, layout, and assembly documentation.

The fabrication stack-up and copper thickness were selected to support the current levels of the charger, while maintaining adequate spacing between primary and secondary domains. Special attention was given to solder mask clearance, silkscreen legibility, fiducial placement, and component footprint consistency to reduce the risk of assembly errors. The board outline, mounting holes, and connector positions were also verified against the mechanical enclosure before release.

### 9.0.2 Design for Manufacturability

DFM was applied to ensure that the PCB could be fabricated and assembled with high yield and low risk of rework. This included the use of standard component footprints, sufficient pad-to-pad spacing, and conservative trace widths in high-voltage and high-current areas. The layout avoided unnecessarily dense routing in regions that would complicate soldering or inspection, especially around the power stage, transformer, and control circuitry.

High-voltage design rules were respected during fabrication planning, including creepage and clearance constraints between live conductors and isolated domains. Copper pours were shaped to avoid sharp corners and narrow neck-downs that could create current bottlenecks or reduce process robustness. The design also accounted for solder mask expansion and component courtyard dimensions so that pick-and-place assembly could proceed without interference.

### 9.0.3 Design for Assembly

DFA considerations were incorporated to make the board easier to populate, inspect, and rework. Components with polarity sensitivity, such as diodes, electrolytic capacitors, ICs, and connectors, were placed with clear orientation markers and consistent reference directions. Large power components were grouped logically to reduce placement complexity and to simplify thermal and electrical debugging after assembly.

The component library was standardized so that footprints, pad sizes, and recommended land patterns matched the intended package types. This reduced the likelihood of footprint mismatches or tombstoning during reflow. Where possible, parts were selected in packages that are compatible with automated assembly and rework, such as QFN, SOIC, SOT-23, and 2512/1206 resistor and capacitor packages. Larger through-hole or mechanically stressed components, such as relays, inductors, and connectors, were positioned to improve solder joint strength and mechanical reliability.

### 9.0.4 Design for Test

DFT was implemented through a modular board structure and the inclusion of test points on all critical nodes. The design was partitioned into functional blocks, allowing input front-end, control logic, auxiliary supplies, and power-stage interfaces to be validated independently during bring-up. Test points were added for the main power rails, feedback signals, PWM outputs, fault lines, enable pins, and communication interfaces so that voltage and timing can be verified without probing directly on fine-pitch device pins.

The test points were placed with sufficient spacing for oscilloscope probes and multimeter clips, and they were labeled clearly in the silkscreen and documentation. This improves debugging efficiency and reduces the chance of accidental short circuits during energized testing. In addition, the modular structure allows individual subsystems to be isolated for troubleshooting, which is especially useful when validating the PFC stage, LLC converter, synchronous rectification, and control firmware separately.

### 9.0.5 Component Placement and Assembly Consid-

erations

The assembly process was guided by the electrical and thermal function of each part. High-power components such as MOSFETs, rectifiers, inductors, transformers, and current-sense elements were grouped to minimize current loop area and to support heat spreading. Control ICs and sensing components were placed in quieter regions of the board to reduce interference from switching nodes and high di/dt paths.

Decoupling capacitors were placed as close as possible to the supply pins of each IC to minimize supply impedance and improve transient response. The placement of the microcontroller, gate drivers, and current-sense amplifiers was chosen to keep signal traces short and clean. Passive components were oriented consistently to ease inspection, and sufficient spacing was kept between hot components to avoid thermal coupling and to improve airflow.

### 9.0.6 Assembly Verification

After assembly, the board was inspected for solder quality, alignment, polarity correctness, and continuity before power-up. Initial verification was performed with a continuity test and low-voltage checks on the auxiliary rails. The input stage, low-voltage supplies, and control board were then tested independently before energizing the full power stage. This staged verification approach reduces the risk of catastrophic failure and allows faults to be identified early.

The test strategy also included checking the response of the relay control, precharge sequence, and fault-handling logic before applying full charging power. Once the low-voltage circuitry was confirmed, the converter could be energized gradually with monitoring of input current, bus voltage, switching waveforms, and output behavior. This method supports safe debugging and limits the possibility of damage during the first power-up.

The PCB manufacturing and assembly stage was executed with DFM, DFA, and DFT principles integrated into the design process. JLCPCB was used for board fabrication and component placement, while modular layout and test-point access ensured that the charger could be assembled and validated in a structured manner. This approach improved manufacturability, reduced assembly risk, and supported efficient prototype bring-up and troubleshooting.

### 10 Prototype Testing and Validation

Prototype testing was performed after PCB assembly to verify correct operation of each subsystem and to confirm that the charger met the intended electrical, thermal, and functional requirements. The validation process was intentionally staged so that the design could be brought up safely, starting with low-voltage checks and progressing gradually to full-power operation. This method reduced the risk of hardware damage and made it possible to isolate faults quickly if any subsystem behaved unexpectedly.

### 10.0.1 Testing Sequence

The testing sequence began with continuity inspection and visual verification of the assembled PCB. After confirming solder quality, component orientation, and the absence of shorts on the low-voltage rails, the auxiliary supply was powered independently and checked for correct output voltages. The control board was then powered and the firmware was loaded to verify MCU startup, timer operation, ADC readings, relay control, and communication interfaces.
Once the low-voltage circuitry had been validated, the input power stage was energized with reduced power and monitored carefully. Measurements were taken at multiple locations across the converter, including the AC input, rectified DC bus, primary switching stage, secondary output, and battery connection point. This allowed the design to be verified stage by stage, from input power quality and bus stability to transformer transfer behavior, rectifier performance, output regulation, and battery charging response.
During constant-current charging, the charger maintains a near-constant output current while the battery voltage rises gradually. As the battery approaches its target voltage, the system transitions into constant-voltage mode, where the voltage is held steady and the current naturally tapers down until the battery is nearly full. This behavior confirms that the firmware control loop, sensing chain, and power stage are working together as intended.

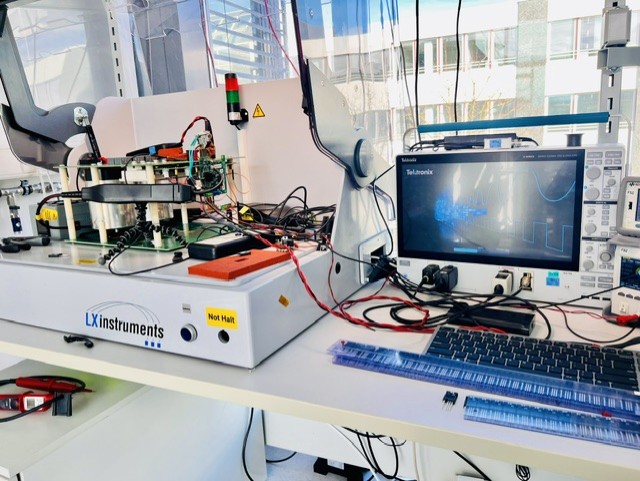
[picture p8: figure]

Figure 11: Laboratory bench setup used for prototype testing.

### 10.0.2 Electrical Validation

Electrical validation focused on the voltage and current waveforms at each important node in the power chain. The AC input was checked to confirm correct rectification and PFC bus formation. The DC bus was then monitored for ripple, regulation, and stability under load. The LLC primary switching node was inspected to confirm resonant operation and to verify that the switching transitions remained consistent with the simulation results.

On the secondary side, output voltage and current were recorded during both constant-current and constant-voltage charging. The transition between charging modes was used as a functional indicator of correct closed-loop control. The battery connection point was also checked to ensure that relay operation, precharge timing, and charger enable logic were functioning correctly during startup and shutdown.

### 10.0.3 Thermal Validation

Thermal measurements were taken to identify hot spots across the primary switches, transformer, synchronous rectifier, and auxiliary power components during load testing. This information was used to evaluate loss distribution and confirm that the layout and cooling strategy were suitable for continuous operation. The thermal survey also highlighted components that may require revised copper area, airflow management, or package selection in the next hardware revision.

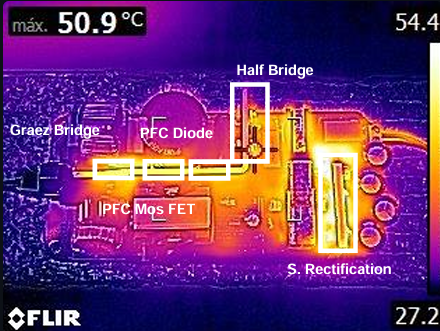
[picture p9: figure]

Figure 12: Thermal measurements at 24 V output and 5 A load, with 25◦C ambient temperature.

### 10.0.4 Functional Results

The prototype results confirmed the overall operating principle of the charger. The constant-current phase provided stable charging current as the battery voltage increased, and the constant-voltage phase reduced the current naturally near the top of charge. This validates both the sensing architecture and the firmware logic used to transition between charging states.

In addition, the thermal image indicates the distribution of heat among the major power components, which is important for assessing long-term reliability. Areas with elevated temperature can be linked to conduction loss, switching loss, or insufficient copper spreading, while cooler regions indicate effective heat distribution and acceptable device loading. These results provide direct feedback for possible optimization in a future PCB revision.

Prototype testing and validation demonstrated that the charger could be brought up safely in stages and that the major functional blocks operated correctly under laboratory conditions. Electrical measurements confirmed stable converter behavior across the input, DC bus, primary stage, and output stage, while thermal testing provided insight into loss distribution and cooling performance. Together, these results show that the design is functionally sound and ready for further refinement or extended endurance testing.

Figure 13 shows the charger installed in the final e-bike prototype, where the PCB modules are clearly visible during validation testing. This setup demonstrates the mechanical integration of the charger and confirms that the

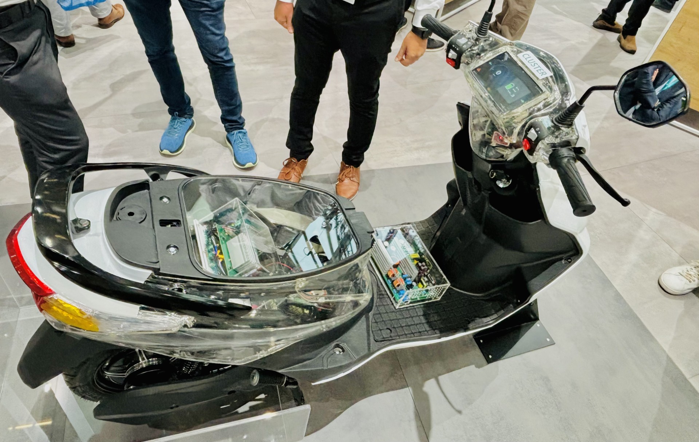
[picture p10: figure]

Figure 13: The charger integrated into the final e-bike prototype, with the charger PCBs clearly visible during validation testing.
design is suitable for real-world use in the full system.

### 11 Data Analysis and Test Automation

The final stage of the design process focused on data analysis and test automation, which were used to support prototype validation, improve measurement repeatability, and accelerate debugging during bring-up. As the hardware was tested across multiple operating points, manual logging became increasingly impractical, especially when comparing charging behavior, thermal performance, and converter waveforms over repeated experiments. To address this, Python was used as a lightweight automation layer between the laboratory instrumentation and the analysis workflow.

### 11.0.1 Test Automation Framework

Python scripts were developed to automate test capture, organize measurement data, and standardize result processing. The scripts were used alongside bench instruments such as oscilloscopes, multimeters, temperature probes, and power supplies to record electrical and thermal measurements in a structured format. This reduced operator workload during testing and improved consistency between measurement runs, particularly when the same test sequence needed to be repeated at different load conditions, input voltages, or battery states.

The automation workflow also made it easier to synchronize measurements from multiple sources. For example, voltage, current, and temperature data could be captured during the same test interval and then associated with a specific operating point. This was especially useful during converter bring-up, where small changes in duty cycle, load level, or charging mode could significantly affect performance. By organizing the measurements in a repeatable format, the test process became more efficient and easier to review.

### 11.0.2 Measurement Processing

The collected data was then processed to extract trends and evaluate the behavior of the charger under different conditions. Python was used to clean raw measurement files, align datasets from different instruments, and generate plots for design review. This allowed the measured results to be compared directly against simulation outputs and expected design targets.

Typical analysis tasks included waveform inspection, average and ripple calculations, thermal trend analysis, and charging profile evaluation. Voltage and current waveforms were used to confirm correct converter operation and to identify transient effects during mode transitions. Thermal data was analyzed to locate hot spots and assess whether the layout and cooling approach were adequate for continuous operation. In addition, charging curves were reviewed to verify the transition between constant-current and constant-voltage modes.

### 11.0.3 Example Test Activities

The automation scripts supported several recurring test activities throughout development:

- Capture voltage and current waveforms at the AC input, DC bus, switching stage, output stage, and battery connection point.
- Log thermal data from the primary power devices, transformer, rectifier stage, and auxiliary supply components.
- Compare simulated and measured converter behavior across load conditions and charging states.
- Generate plots and summary figures for lab documentation, report preparation, and design review.
- Track repeated test runs to identify variation between measurements and highlight unstable operating conditions.

### 11.0.4 Benefits to Validation

Using Python for test automation improved the overall validation workflow in several ways. First, it reduced the time required to collect and organize data during iterative testing. Second, it improved repeatability by ensuring that test conditions, file naming, and analysis steps were applied consistently. Third, it made debugging faster by allowing the measured behavior of individual subsystems to be reviewed immediately after each test run.

This approach was particularly valuable for a mixedsignal power electronics design, where electrical performance, thermal behavior, and firmware response must all be evaluated together. Automated analysis made it possible to correlate these domains and identify design limitations more efficiently. As a result, the validation process not only confirmed correct system operation but also provided actionable feedback for future hardware revisions and firmware improvements.

Data analysis and test automation formed the final layer of the development workflow. Together, they transformed raw lab measurements into structured evidence of performance, supported comparison between simulation and hardware results, and improved the efficiency of prototype validation. In combination with the staged testing strategy used earlier, this automation framework helped ensure that the charger was evaluated systematically and documented thoroughly.
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

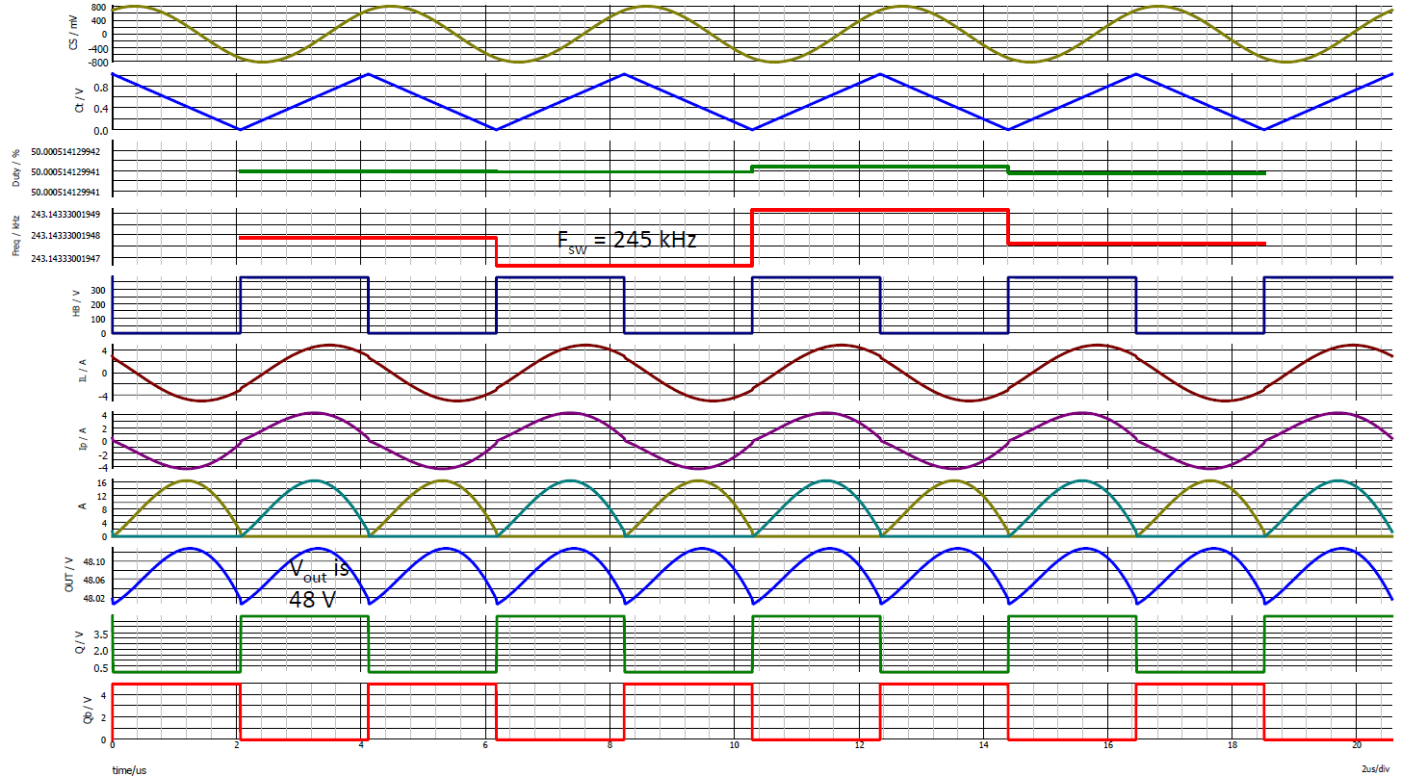
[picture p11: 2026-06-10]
Spice simulations/screenshot 2.png

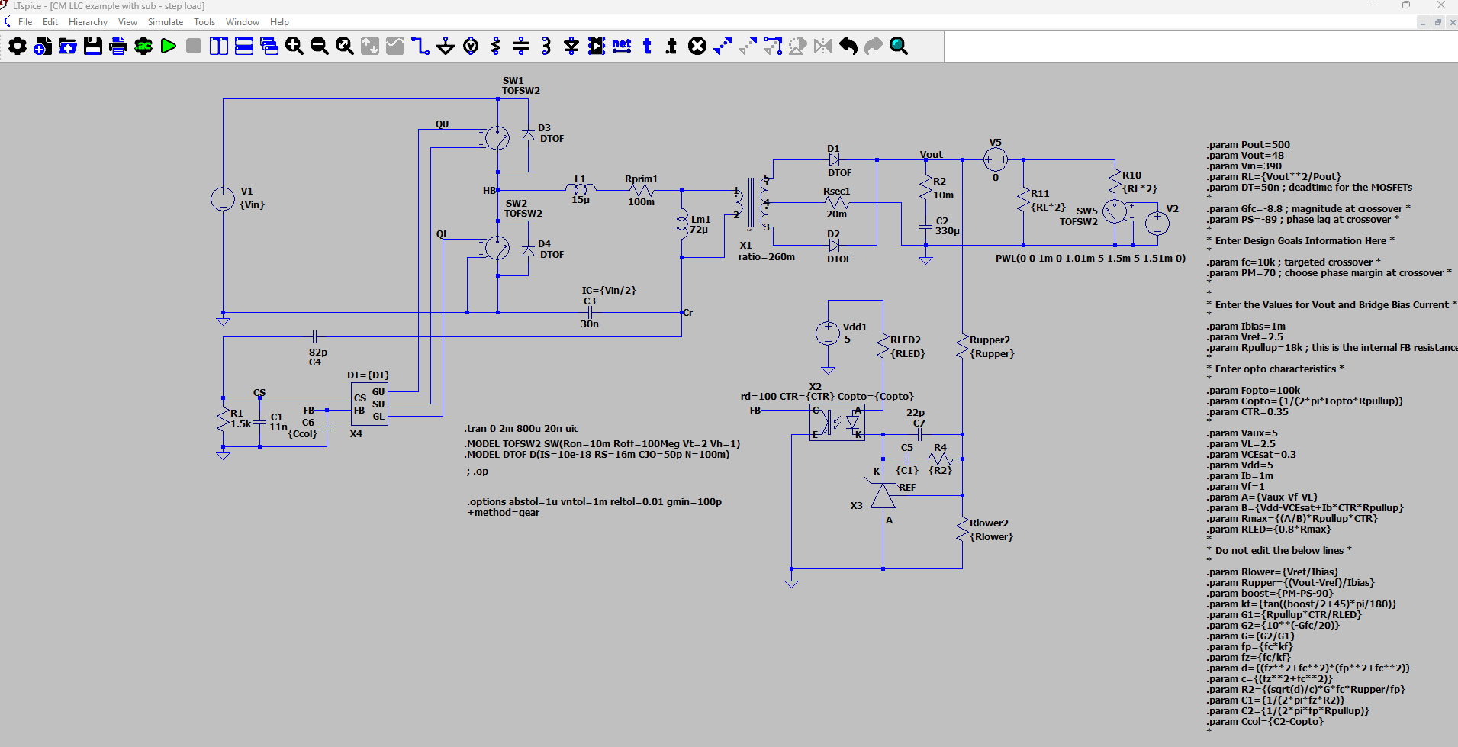
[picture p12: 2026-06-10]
Spice simulations/screenshot.png

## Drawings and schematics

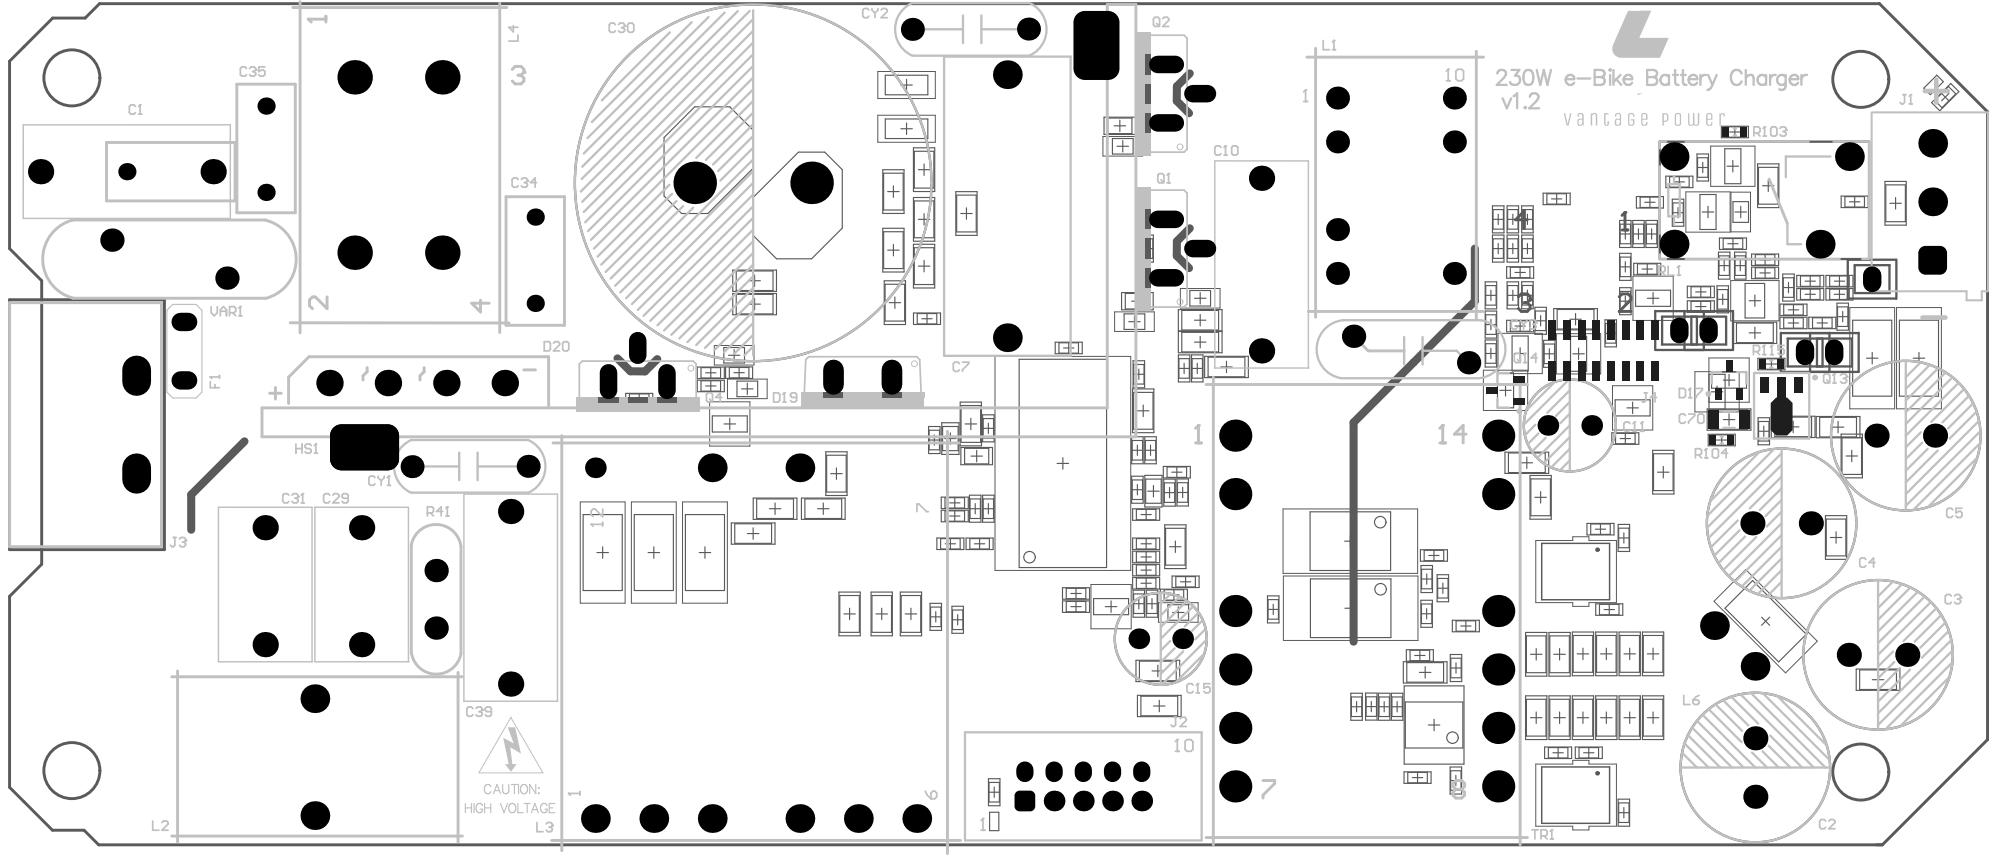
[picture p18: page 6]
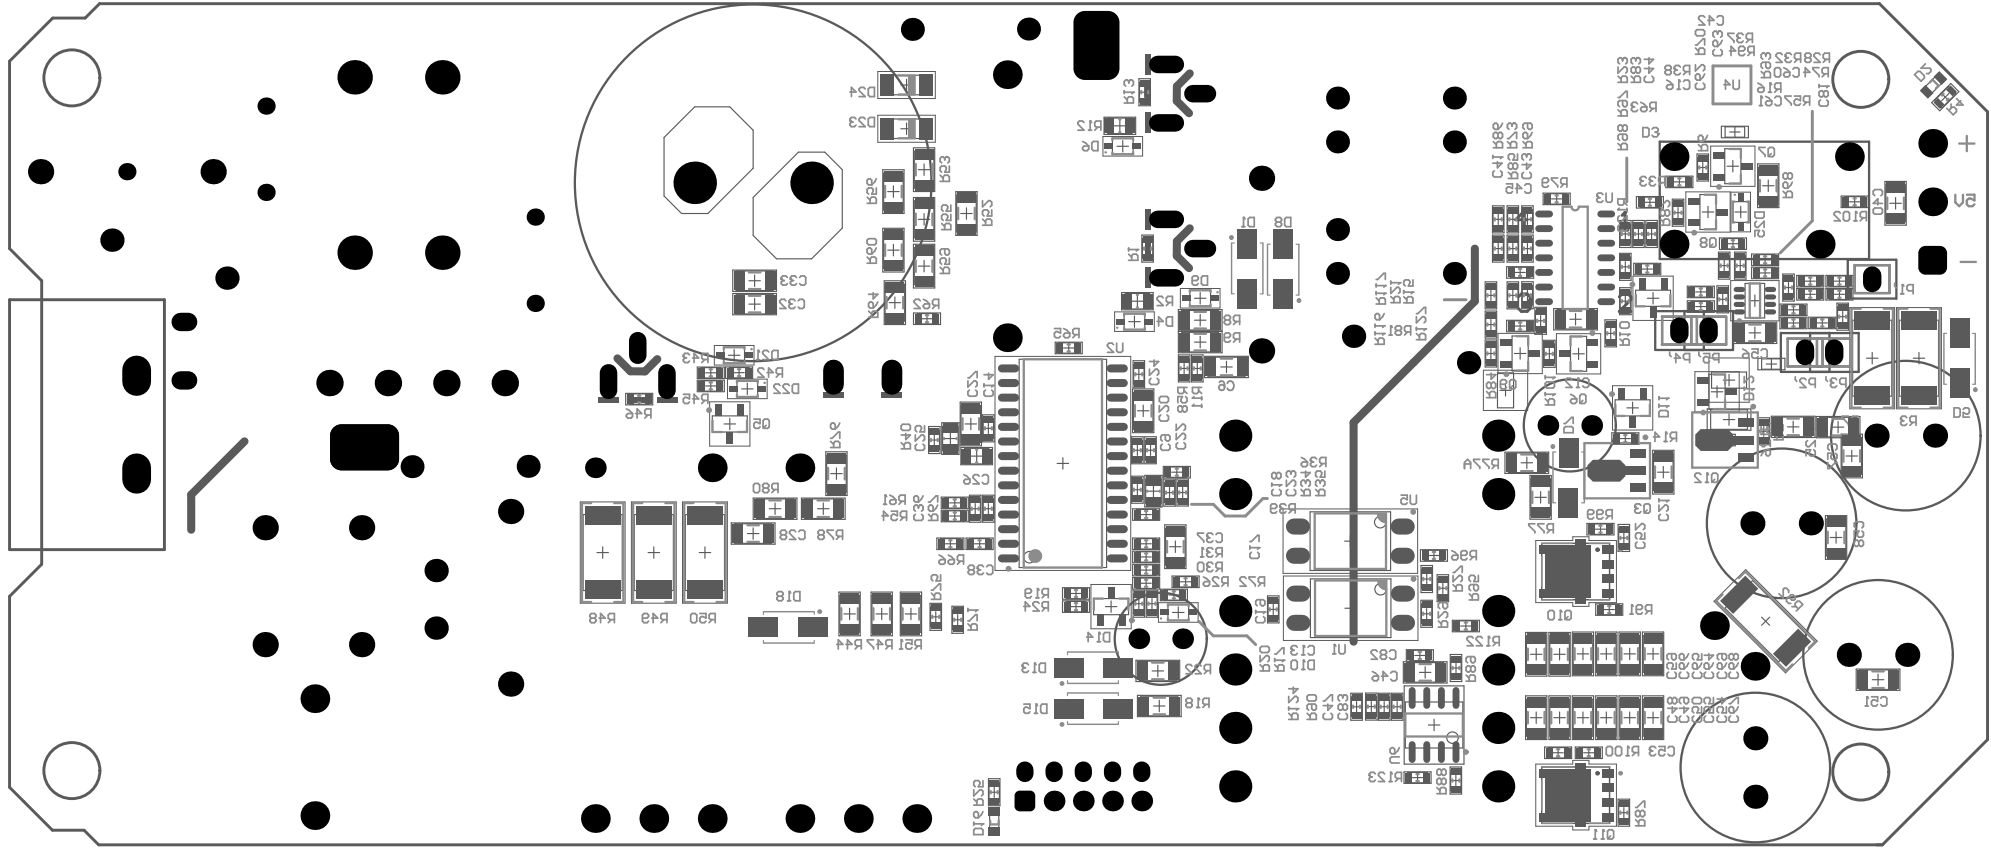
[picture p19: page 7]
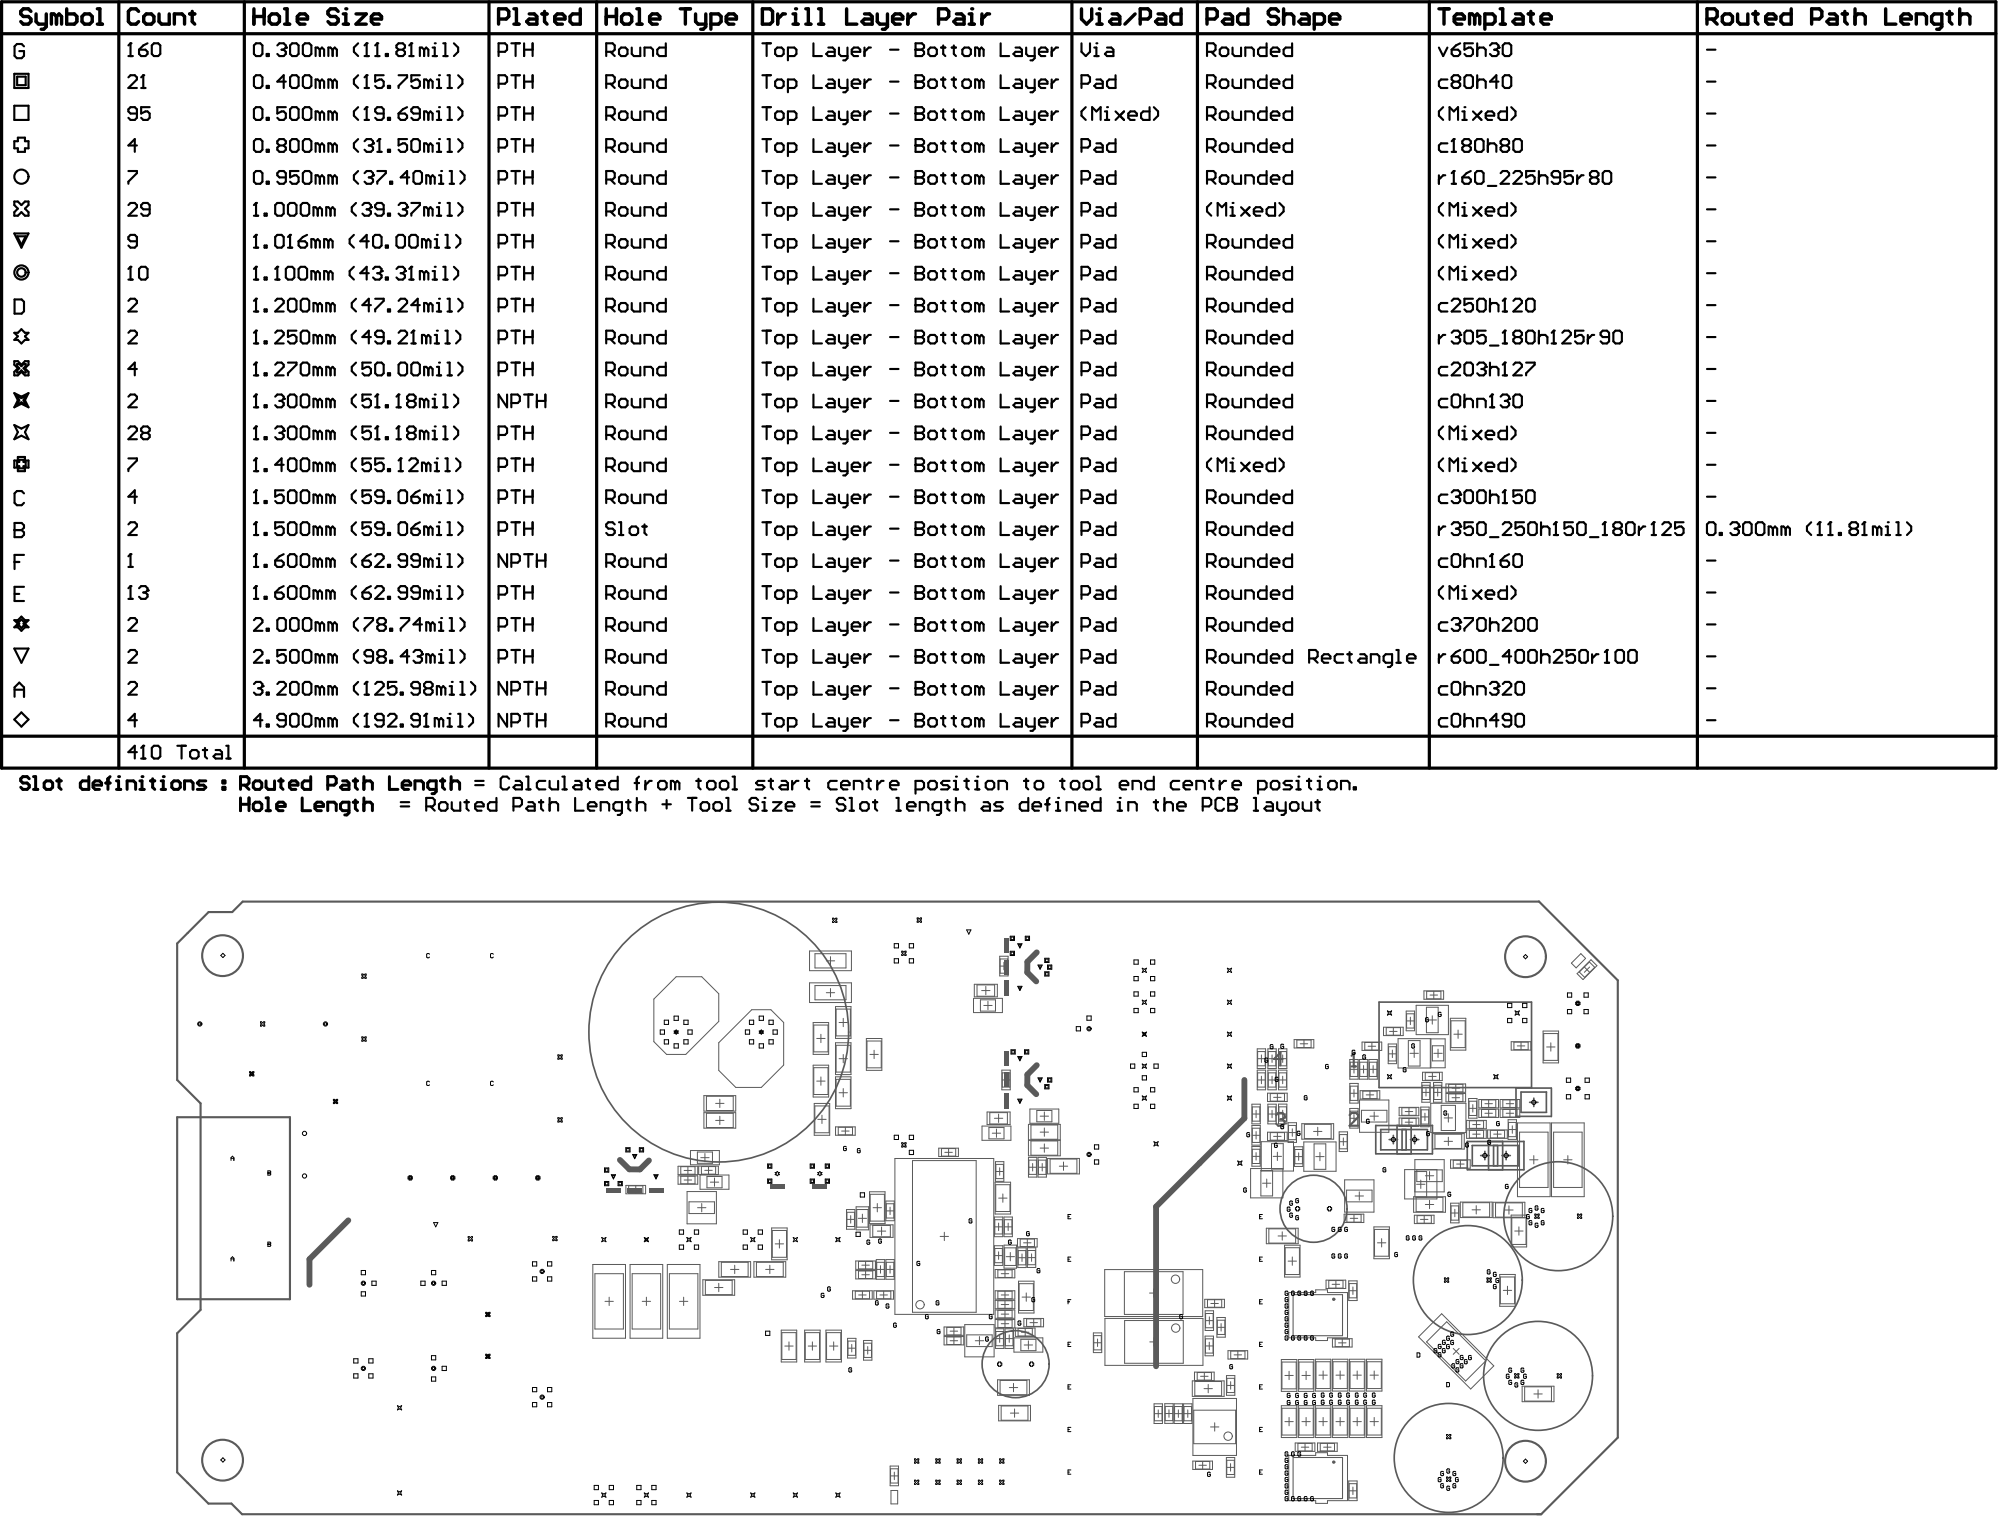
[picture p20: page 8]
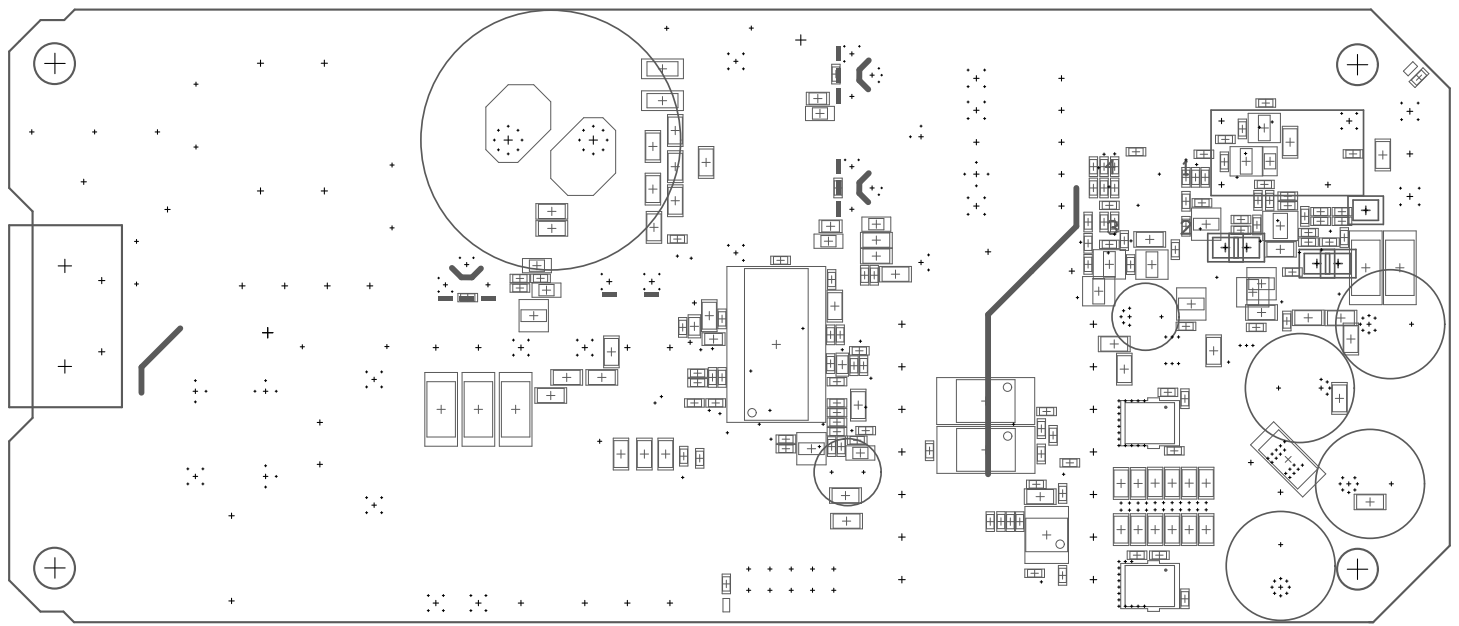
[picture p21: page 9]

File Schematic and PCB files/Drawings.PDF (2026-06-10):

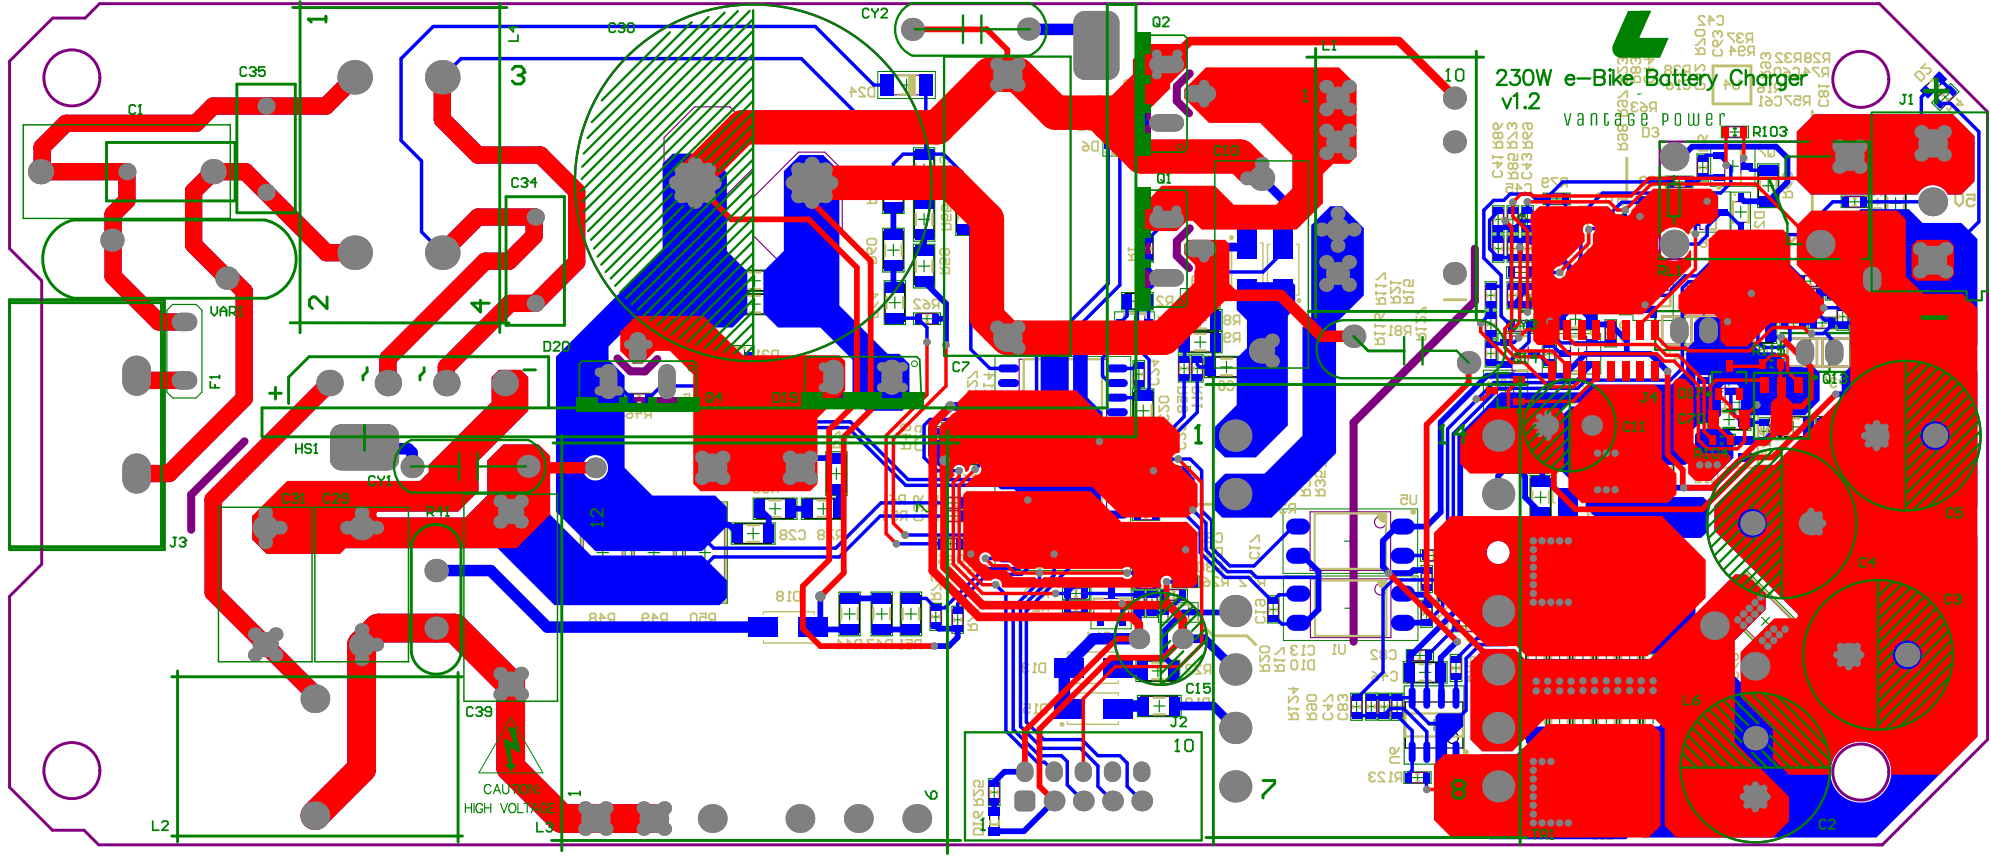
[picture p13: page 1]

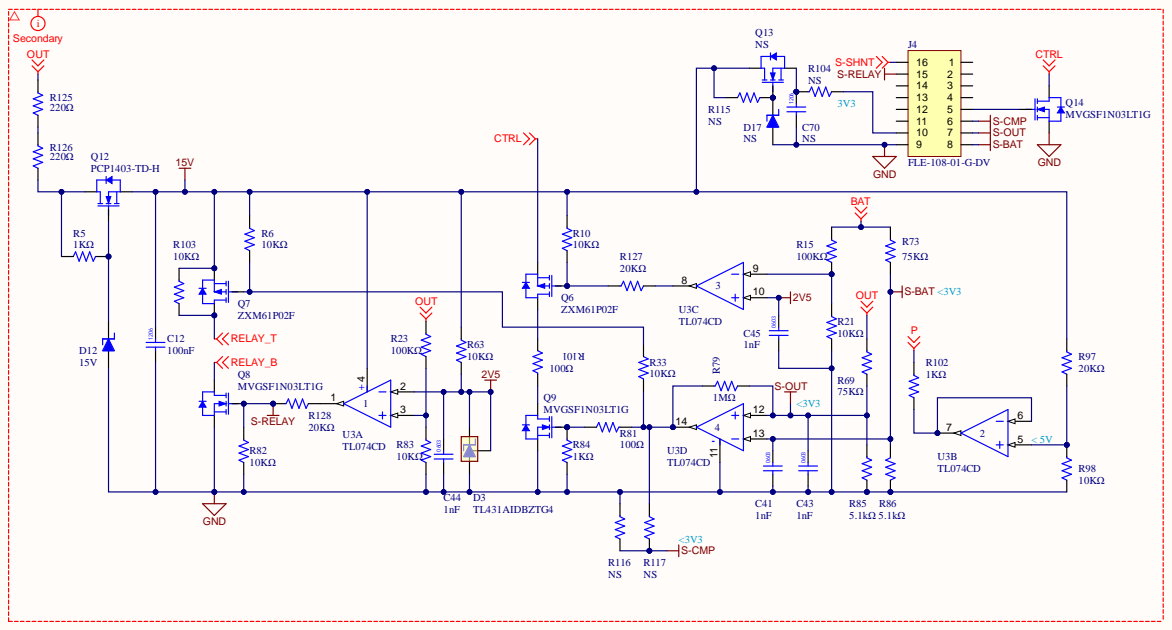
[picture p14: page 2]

DWG . N O . | R E V . | * S H T.

T H IS DOC U MEN T AN D T HE D ATA D ISCLOSED HEREI N OR HEREW I T H IS T HE PROPER TY OF ALT I U M LI M I TED AN D M AY BE F REELY D IST R IBU TED I N W HOLE. NO R IGH TS ARE RESERVED OR EXPRESS OR I MPLIED WARAN TEE GIVEN . | | REVISI O | N DESC R IPT I O N | DAT E | APPR OVED

REV. SHT. DWG. NO.

DATE | PRO JECT * | AD D RESS 1 2 APPROVALS AD D RESS AD D RESS 3 AD D RESS 4

ENG : | --/--/--
** DSN: | --/--/--

CHK: * | --/--/--

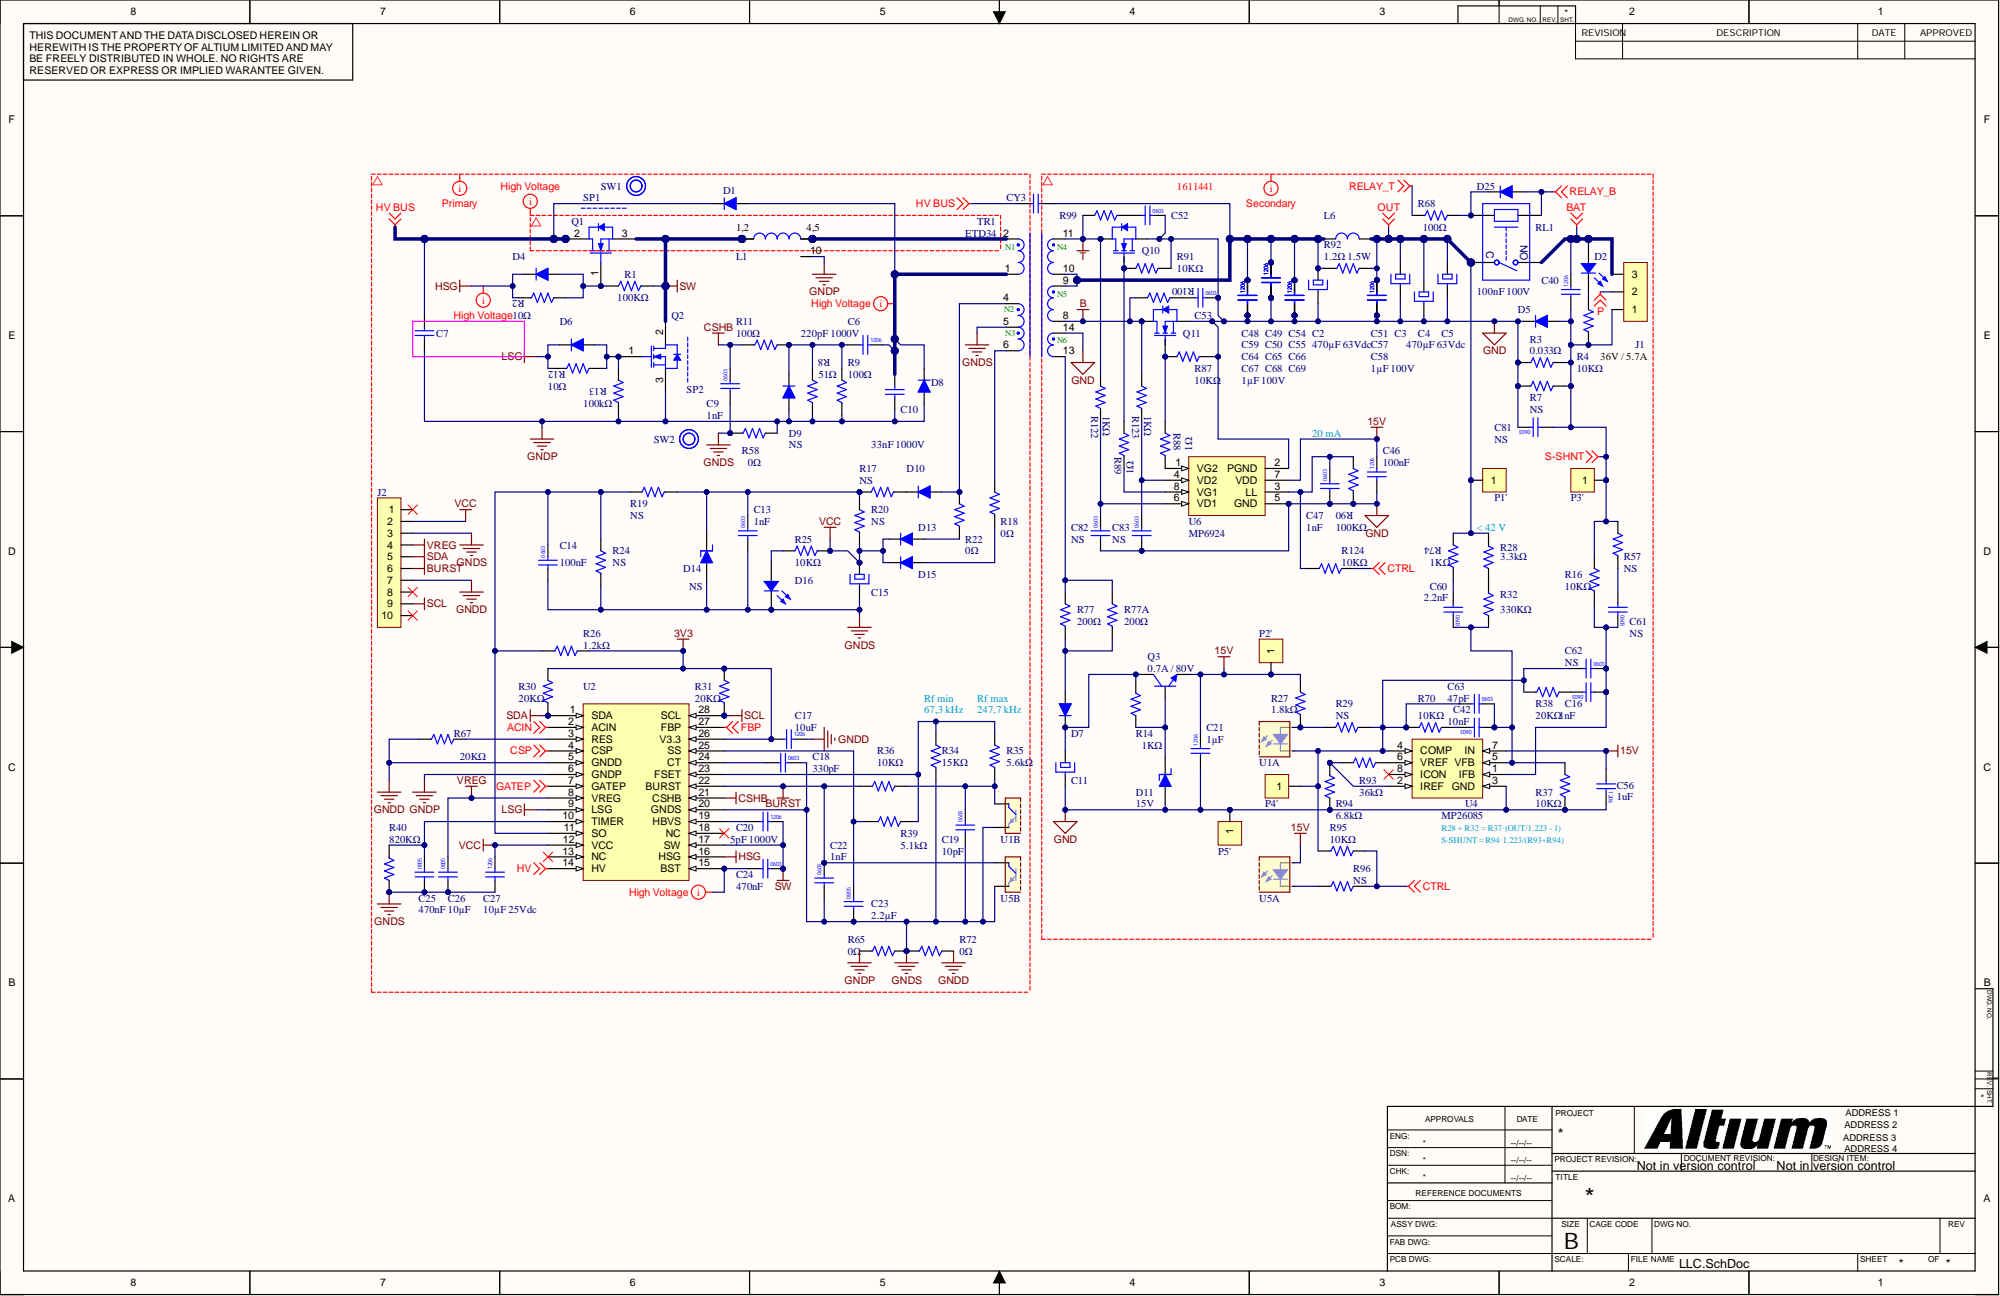
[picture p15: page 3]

DWG. NO. | REV. | SHT.

THIS DOCUMENT AND THE DATA DISCLOSED HEREIN OR HEREWITH IS THE PROPERTY OF ALTIUM LIMITED AND MAY BE FREELY DISTRIBUTED IN WHOLE. NO RIGHTS ARE RESERVED OR EXPRESS OR IMPLIED WARANTEE GIVEN. | | REVISION | DESCRIPTION | DATE | APPROVED

GATEP

VREG 8 | C22 1nF | R39 5.1kΩ

TIMER 10 | | 1206
SO 11 | 5pF 1000V

REV. SHT. DWG. NO.

DATE | PROJECT * | ADDRESS 1 ADDRESS 2 APPROVALS ADDRESS 3 ADDRESS 4

ENG: * | --/--/--

DSN: * | --/--/--

CHK: * | --/--/--

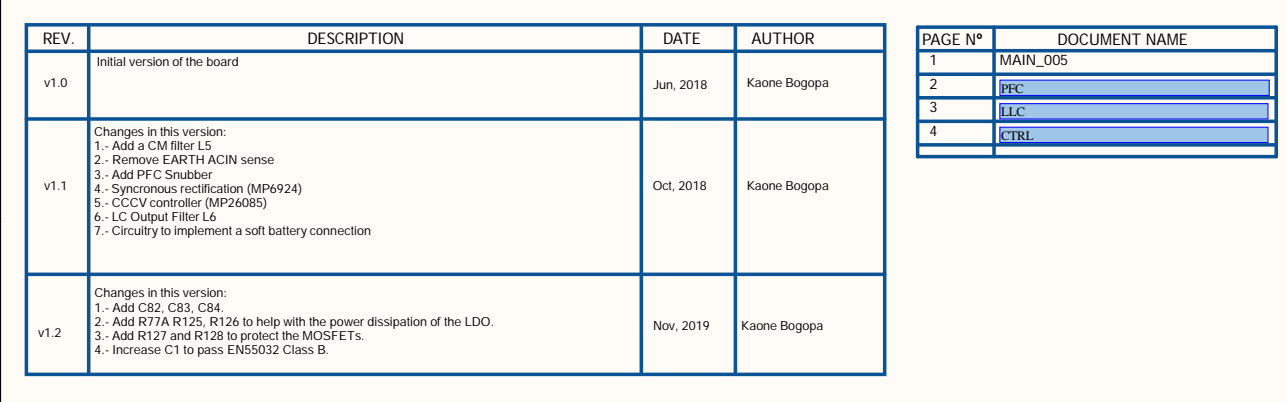
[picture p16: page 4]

DWG. NO. | REV. | SHT.

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

Initial version of the board

Changes in this version:
1.- Add a CM filter L5
2.- Remove EARTH ACIN sense
3.- Add PFC Snubber
4.- Syncronous rectification (MP6924)
5.- CCCV controller (MP26085)
6.- LC Output Filter L6
7.- Circuitry to implement a soft battery connection

1.- Add C82, C83, C84.
2.- Add R77A R125, R126 to help with the power dissipation of the LDO.
3.- Add R127 and R128 to protect the MOSFETs.
4.- Increase C1 to pass EN55032 Class B.

REV. SHT. DWG. NO.

DATE | PROJECT * | ADDRESS 1 ADDRESS 2 APPROVALS ADDRESS 3 ADDRESS 4

ENG: Kaone Bogopa | --/--/--

DSN: * | --/--/--

CHK: * | --/--/--

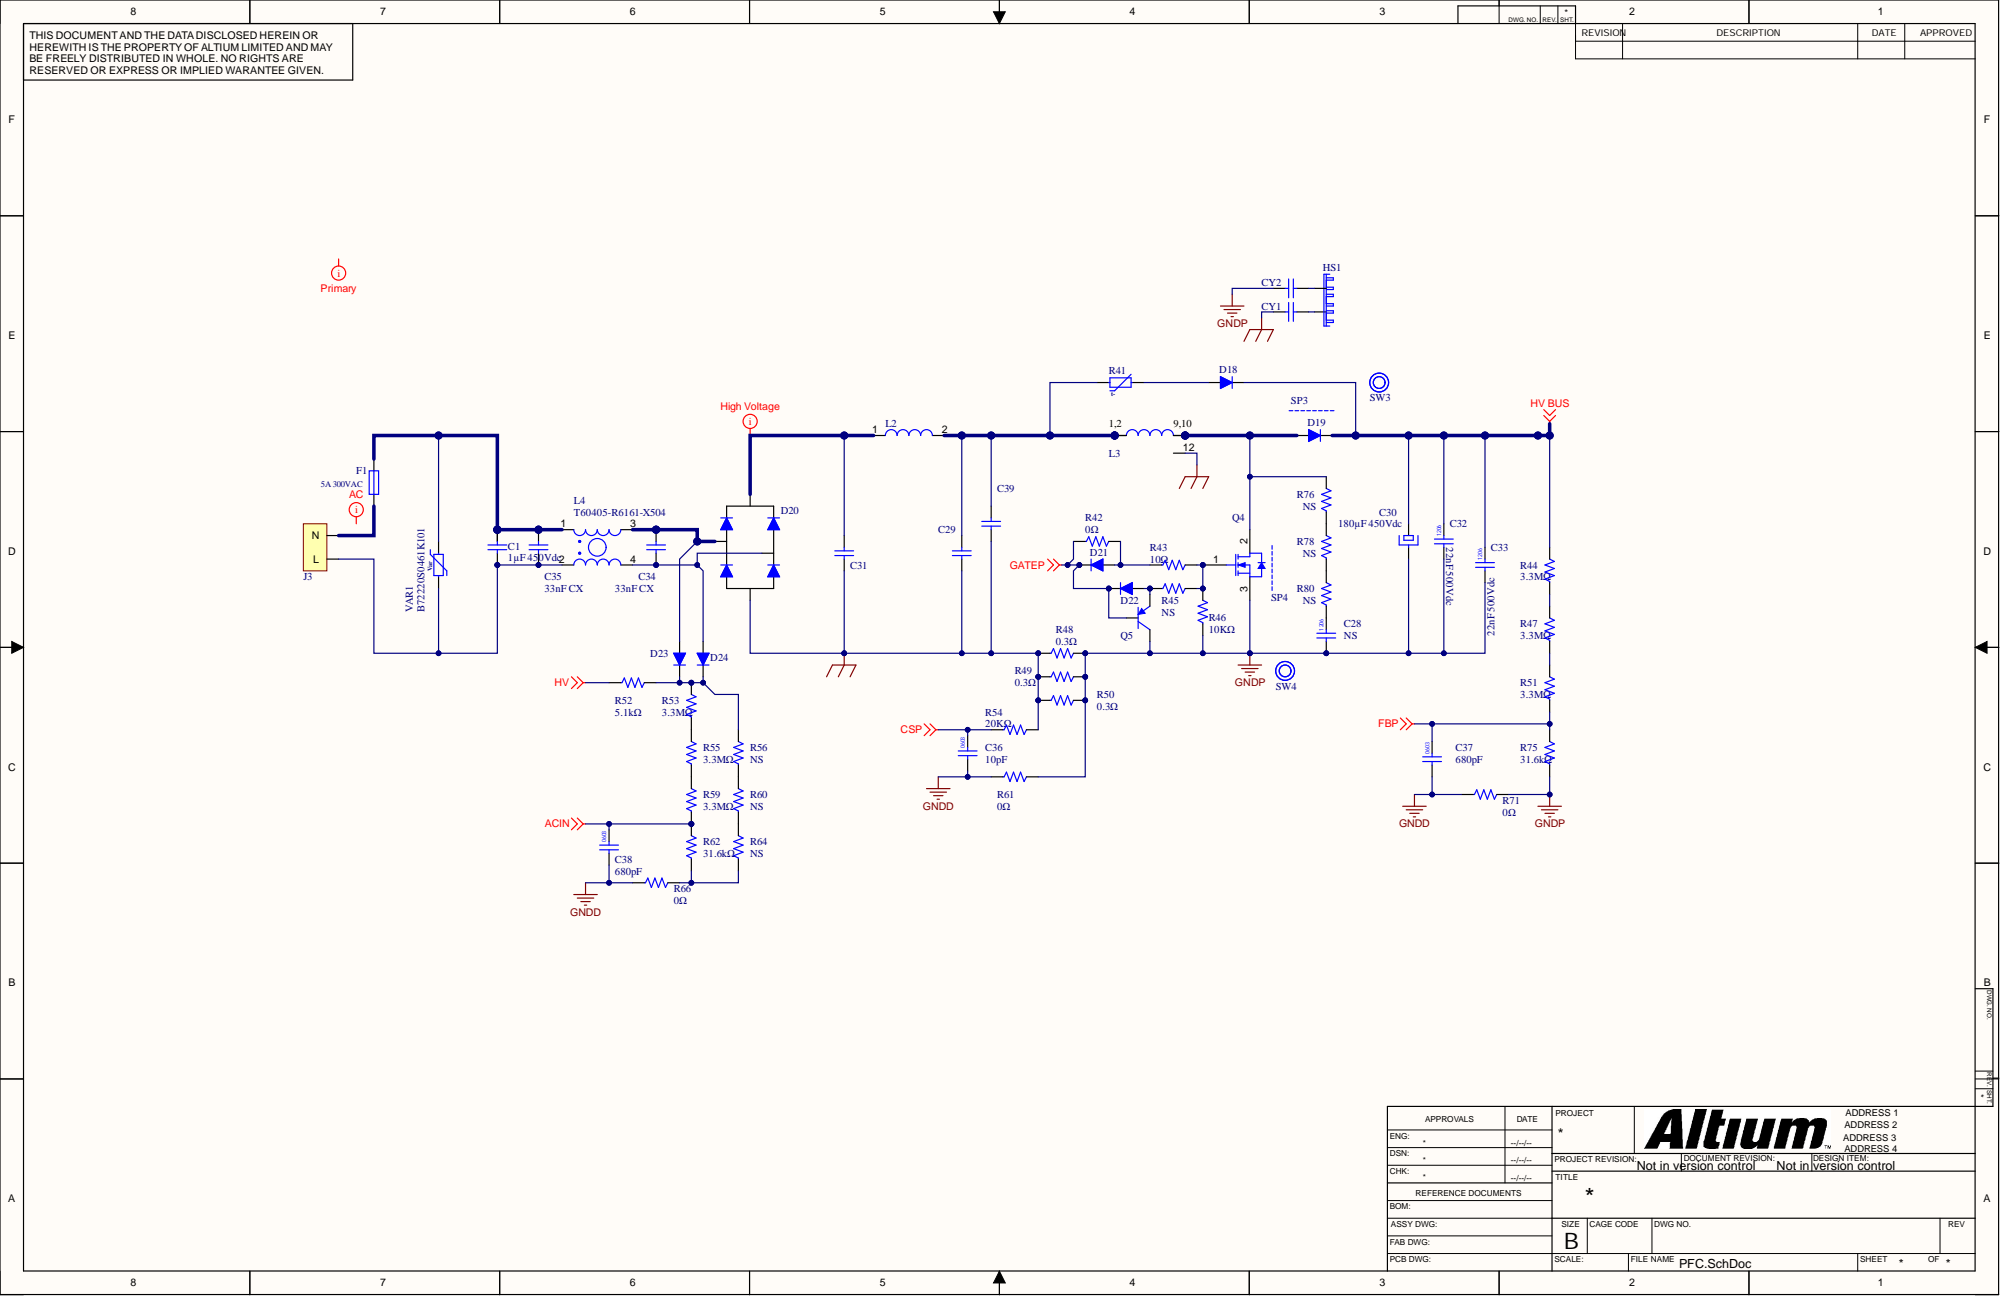
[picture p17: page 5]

DWG . N O . | R E V . | S H T.

T H IS DOC U MEN T AN D T HE D ATA D ISCLOSED HEREI N OR HEREW I T H IS T HE PROPER TY OF ALT I U M LI M I TED AN D M AY BE F REELY D IST R IBU TED I N W HOLE. NO R IGH TS ARE RESERVED OR EXPRESS OR I MPLIED WARAN TEE GIVEN . | H S 1 | REVISI O | N DESC R IPT I O N | DAT E | APPR OVED

REV. SHT. DWG. NO.

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

ENG : | --/--/--
** DSN: | --/--/--

CHK: * | --/--/--
